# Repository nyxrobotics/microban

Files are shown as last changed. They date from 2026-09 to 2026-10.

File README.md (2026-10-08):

# Microban: A Compact, Fully 3D-Printable Open-Source Humanoid Robot





<p align="center">
  
  
  
</p>
  
Welcome to the **Microban** project! 

Microban is a ~30cm tall open-source humanoid robot created by [Marc Duclusaud](https://github.com/MarcDcls) as a member of the Rhoban team at LaBRI, University of Bordeaux, and designed specifically for makers, students, and robotics enthusiasts. The core philosophy behind this project is accessibility: the total cost of the robot is kept relatively low ($550-$600), all components are 3D-printable or easily sourced, and the assembly process is guided with detailed instructions. This means that anyone with a standard desktop 3D printer and a few basic tools should be able to build their own Microban from scratch.

The idea behind Microban is to provide a platform for learning and experimentation in robotics. By making the design open, users are encouraged to modify, improve, and share their own versions of the robot. Whether you're interested in programming, mechanical design, or electronics, Microban offers a hands-on experience that can help you develop your skills in a fun and engaging way.

The main features of Microban are:
*   🤖 **100% Open-Design**: Mechanics, 3D models, and documentation are entirely free to use and modify.
*   🔧 **DIY & Maker Friendly**: Guided assembly instructions, fully 3D-printable parts and cheap components.
*   📏 **Compact Size**: Microban is only 30cm tall and can be recharged via USB-C, making it the perfect desktop companion for robotics experimentation.

To see the robot take its first steps, check out this YouTube video: [https://youtu.be/1pnFrT_jfXQ](https://youtu.be/1pnFrT_jfXQ)

---

## 🛠️ Components Overview

Here is a quick overview of what is in the robot:

| Component | Quantity | Description / Notes |
| :--- | :---: | :--- |
| **3D Printed Parts** | ~30 | Check the CAD files. Recommended material is PETG-CF. |
| **Servo Motors** | 21 | Dynamixel XC330-T288-T servomotor. |
| **Microcontroller**| 1 | Raspberry Pi Zero 2W. |
| **Board Hat** | 1 | Pollen RPI Robot Hat for Raspberry Pi Zero 2W. |
| **Stereo Camera** | 1 | ELP-3DGS1200P01-H120 dual-lens (binocular) USB camera module, ~59mm measured baseline, mounted in the neck. |
| **Power Supply** | 3 | 18650 3.7V Lithium-ion Batteries. |
| **Battery Holder** | 1 | 3x18650 Battery Holder. |
| **USB-C Charger** | 1 | Standard USB-C charger. |
| **BMS** | 1 | Battery Management System for 3x18650 batteries. |
| **Plastic Screws**| ~200 | Standard plastic screws for assembly. |
| **Steel & POM Shims** | 12 | Alternative to needle bearings for motors without idler horns. | 

A full, detailed Bill Of Materials (BOM) with links to purchase and prices is available [here](docs/bom.md)

---

## 📁 CAD Files

Capture d’écran du 2026-06-15 13-33-16

The CAD files for Microban are in the `cad/` directory of this repository. It contains all the printable parts in both STL and STEP formats.

A visual representation of the 3D model can be found in the [Onshape assembly](https://cad.onshape.com/documents/d424992a192a8ce34ffce163/v/7de3e6e40f0e1185d169e6d9/e/b34620a03cc3a684006c5867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). This interactive assembly allows you to explore the robot's design in detail, providing a better understanding of how the parts fit together. It also serves as a reference for assembly, helping you visualize the final product and ensuring that you can correctly identify each component during the build process.

An emphasis is placed on the range of motion of the 21 degrees of freedom of the robot, which include a 2-DOF (roll + pitch) neck carrying a forward-facing stereo camera. It allows for a wide variety of movements, making it suitable for various applications. Stops are integrated into the design to control which self-collisions are likely to occur, ensuring that the robot can move safely without damaging itself. The design also takes into account the cable routing for the servo motors, ensuring that the wires are neatly organized and do not interfere with the robot's movements.

---

## 🚀 Getting Started 

> **Need help during the build?** 
> If you run into any issues while sourcing components, printing parts, or assembling your Microban, don't hesitate to ask the community in the **[Q&A Discussions section](https://github.com/Rhoban/microban/discussions/categories/q-a)**!

To build your own Microban, you will need to follow these steps:

1. **Source the hardware:** Gather the components listed in the [BOM](docs/bom.md). Links are provided to purchase each item, but feel free to source them from your preferred suppliers. Some components, like the Dynamixel motors, may have specific distributors depending on your location, which can impact the total cost. 

2. **Print the parts:** Head over to the `cad/stl/` folder and print all the parts using a 3D printer. The recommended filament is PETG-CF (carbon-fiber-filled PETG) with a layer height of 0.12mm and 100% infill. PETG-CF is abrasive, so print with a hardened steel (or similarly wear-resistant) nozzle rather than plain brass. Some parts require specific orientations for printing to ensure strength and proper fit. Refer to the [Printing Guide](docs/printing.md) for detailed instructions on how to print each part correctly.

3. **Assemble:** Follow our step-by-step [Assembly Guide](docs/assembly.md) to put the mechanics together.

4. **Deploy the software:** Once the robot is assembled, you can deploy the software on the Raspberry Pi Zero 2W by following the instructions in the [Deployment Guide](docs/deployment.md). 

5. **Drive it:** See the [Usage Guide](docs/usage.md) to run the robot, control it with the keyboard or a gamepad, and learn how to add your own moves.

---

## 🤝 Contributing

This project is community-driven! Whether it's designing a new head, writing code, or simply fixing typos in the documentation, contributions are always welcome. Feel free to fork the repository, make your changes, and submit a Pull Request. 

If you build your own Microban, don't hesitate to share it in the **[Show and Tell section](https://github.com/Rhoban/microban/discussions/categories/show-and-tell)**! 

If you just want to share ideas or chat about the project, you are also more than welcome to join the **[General Discussions](https://github.com/Rhoban/microban/discussions/categories/general)**.

---

## 📄 License & Commercial Use

Copyright (c) 2026 Marc Duclusaud.

This project uses a dual-licensing model to keep the project open for the community while protecting the author's work from unauthorized commercial exploitation.

* **Hardware & Documentation (CAD, STL, Docs):** Licensed under [CC BY-NC-SA 4.0](https://creativecommons.org/licenses/by-nc-sa/4.0/).
* **Software (Source Code):** Licensed under [GNU GPL v3](https://www.gnu.org/licenses/gpl-3.0.html).

To summarize the licenses:

* **Hobbyists, Makers & Researchers:** You are **100% free** to download, 3D-print, build, modify, and hack Microban for your personal, educational, or academic research use. If you share your modifications, you must release them under the same licenses.
* **Commercial Entities & Companies:** You **cannot sell this robot**, sell parts/kits, or use this hardware/software design in commercial products without prior explicit written permission.

### ⚠️ Commercial Inquiries

If you wish to manufacture, distribute, or sell products based on Microban (including selling pre-printed 3D parts, electronics kits, or fully assembled robots), you **must acquire a Commercial License**.

For licensing terms, commercial partnerships, or inquiries, please reach out to me on [LinkedIn](https://www.linkedin.com/in/marc-duclusaud/).

---

## 📚 Citation

If you use Microban in your research, please cite it as follows:

```bibtex
@software{mduclusaud-microban,
    author = {Duclusaud, Marc},
    doi = {10.5281/zenodo.20784789},
    month = jun,
    title = {{Microban: A Compact, Fully 3D-Printable Open-Source Humanoid Robot}},
    url = {https://github.com/Rhoban/microban},
    howpublished = "\url{https://github.com/Rhoban/microban}",
    version = {1.0.0},
    year = {2026}
}
```

---

<p align="center">
  
</p>

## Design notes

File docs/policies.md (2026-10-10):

# 学習したモデル（歩行・起き上がり・PICO）の契約と導入

実機は学習リポジトリ（mjlab_microban）で学習した 3 つのモデルを使う。

| モデル | ファイル | 使う動作 |
|---|---|---|
| 歩行 | `src/agents/walk.onnx` | `WalkMove`（GC300） |
| 起き上がり | `src/agents/getup.onnx` | `GetupMove`（転倒後の起き上がり、立位の保持） |
| PICO | `src/agents/pico_teleop.onnx` | `PicoHybridMove`（PICO の左トリガーで選ばれる全身の遠隔操作） |

3 つとも `src/policy_contract.py` の契約 `microban-policy-1` だけで照合する。
学習側との取り決めの全文は学習リポジトリ側と共有している契約の文書（metadata のキーの一覧）にあり、ここでは実機側の要点を書く。

## 契約
- 版: metadata の `microban_policy_contract` が `microban-policy-1`。観測・行動・目標の意味を変えたら、両方のリポジトリで手で上げる。
- 種類とレシピ: `microban_policy_kind`（walk / getup / pico）と `microban_recipe`。受け付けるレシピ id は `policy_contract.RECIPES` に 1 つずつ。
  PICO のモデルは、凍結した歩行器の出力に、学習した小さな補正の網（入力 81、隠れ層 64・64）の出力を足したもので、1 つのグラフになっている。レシピ id `microban-pico-arm-overlay-residual-track-velocity-1` はこの構造を表し、補正の網のない以前のモデル（`microban-pico-arm-overlay-track-velocity-1`）は拒否する。
- HOME: `home_pose` の全精度のスタンプと `default_joint_pos` が `config/home_pose.yaml` と 1e-6 以内で一致すること。別の HOME で学習したモデルは拒否する。
- 目標の式: どのモデルも `target = clip(HOME + raw * 1.0, -π, +π)`（18 関節、ソフトウェアのクリップなし、±π はサーボの 1 回転の範囲）。前回の行動の観測は生の出力。PICO だけは腕の 6 関節にこの式を使わない（下の「PICO の実行時の動き」）。
- 観測の並び: `observation_schema_json`（walk 63、getup 60、pico 81）と `observation_joint_names`。
- 合格: `gate_status=pass` と判定レポートの sha256。チェックポイントの名前と sha256。
- PICO だけ: 凍結した歩行器のチェックポイント（`pico_walk_checkpoint_sha256`）、足の目標の座標（HOME の体幹の傾きから決まる）と範囲、腕の目標（`pico_arm_target_json`: 関節の箱と速さ 4 rad/s が `pico_arm_contract` と同じ）、生の行動の上限（`pico_raw_action_guard_json`）、段の時刻（`critic_warmup / arm_start / foot_start / foot_tighten / total`。保存点が最後の段のものであること）、全部の追加列が学習されたこと。

実機側のソースのハッシュは使わない。互換性は契約の版と次の起動時の自己テストで確かめる。

## 起動時の自己テスト
各モデルには、書き出したチェックポイントの評価のロールアウトから取った観測 8〜64 行と、それに対する学習時の actor の出力が入っている。
実機は読み込むときにそれを ONNX Runtime に通し、行ごとに `max|ORT − 記録| ≤ 1e-4 + 1e-5 × max|記録|` を確かめる（PICO は加えて出力が上限以内）。
記録の観測は、重力のノルムが 1、関節角が可動範囲 + 5° の内側、関節速度が 12.1 rad/s 以下であること。
PICO の記録は、腕の目標が腕の箱の中にあり、腕の目標が 0 でない行と足の目標が 0 でない行を含むこと。

## manifest と導入
導入の道具（学習リポジトリの `scripts/retrain_all_for_home.py`）は次だけを書き、実機の .py もテストも書き換えない。

- `src/agents/walk.onnx`、`getup.onnx`、`pico_teleop.onnx`
- `src/agents/manifest.json`: 契約、HOME の tag、学習側の commit、試運転かどうか、各ファイルの sha256 とチェックポイントの sha256
- `config/home_pose.yaml`（schema 2）

実機はモデルを読むたびに、ファイルの sha256・チェックポイントの sha256・HOME の tag を manifest と照合し、
PICO は凍結した歩行器が導入された walk.onnx と同じチェックポイントであることも確かめる。
試運転のパッケージ（`dry_run`）は環境変数 `MICROBAN_ALLOW_DRYRUN_POLICY=1` のときだけ受け付ける（導入の検証とテストの実行のためだけ）。

検証（モーターのバスは開かない）:

```bash
PYTHONPATH=src uv run --locked python tools/validate_policies.py src/agents
PYTHONPATH=src uv run --locked --with pytest python -m pytest -q tests
make teleop-validate HOST=microban   # 作業機と Raspberry Pi の両方で validate_policies を実行
```

`make teleop-validate` は作業ツリーをそのまま rsync するので、`git status --porcelain=v1 --untracked-files=all` が空の状態で実行する。
通ってから `make teleop-run HOST=microban` で制御を始める。

### PICOだけを再学習した場合

同じHOMEと同じ歩行器からPICOだけを再学習した場合は、3モデル一括の
`retrain_all_for_home.py`ではなく、PICO専用の導入道具を使う。書き出しに使った
stage gateも渡すため、別の判定結果やcheckpointから作ったONNXは導入できない。

```bash
TRAINING_REPO=/absolute/path/to/mjlab_microban
PICO_RELEASE="$TRAINING_REPO/artifacts/pico_release/<run>"
TRAINING_COMMIT=<学習開始時にrunが記録した40桁のcommit>

PYTHONPATH=src uv run --locked python tools/install_pico_policy.py \
  "$PICO_RELEASE/pico_teleop.onnx" \
  "$PICO_RELEASE/model_14999_gate.json" \
  --training-repo "$TRAINING_REPO" \
  --training-branch tracking-v13c \
  --training-commit "$TRAINING_COMMIT" \
  --check-only

PYTHONPATH=src uv run --locked python tools/install_pico_policy.py \
  "$PICO_RELEASE/pico_teleop.onnx" \
  "$PICO_RELEASE/model_14999_gate.json" \
  --training-repo "$TRAINING_REPO" \
  --training-branch tracking-v13c \
  --training-commit "$TRAINING_COMMIT"

PYTHONPATH=src uv run --locked python tools/validate_policies.py src/agents
PYTHONPATH=src uv run --locked --with pytest python -m pytest -q tests
```

導入道具は、既存のwalk/getupを先に検証してそのbytesとmanifest欄を変えずに候補bundleへコピーし、
新しいPICOの契約、CPU自己テスト、stage gate hash、凍結walkerのcheckpoint hashを検証する。
さらにstage gateが指すcheckpointとrunの`git/mjlab_microban.diff`を読み、ONNX metadataに埋め込まれた
学習開始時のcommit・branch・Git記録hashと一致すること、そのcommitが指定branchに含まれることを確かめる。
現在のbranch先端（学習後の文書commitなど）を学習commitとして記録してはならない。

manifest上端の`training_commit`、`training_branch`、`home_yaml_sha256`、`created`は、保持したwalk/getupを含む
元の3-policy bundleの記録なので書き換えない。後から入れたPICOの出所は
`policy_provenance.pico`にcheckpoint、gate、ONNX、runのGit記録まで別に保存する。

3モデルをまとめた候補bundleが通った後にだけ`pico_teleop.onnx`と`manifest.json`を置き換える。
2ファイルは一度にはrenameできないため、導入前の両bytesとfsync済みjournalを
`src/agents/.pico-policy-install*`へ先に保存する。途中で電源断・killが起きた場合は、次にこの道具を
起動した時点で、完全な新しい組なら検証して確定し、途中の組なら古い組へ戻す。
復旧資料が壊れていて判断できない場合は上書きせず失敗する。正常終了時にはjournalもbackupも残らない。
同じbundleへの導入はlockで直列化し、atomic rename前に止まって残った専用tempも次回起動で除く。
`--check-only`を含むどの起動も、残っているtransactionの復旧だけは先に行う。
したがって差分はこの2ファイルだけでなければならない。

```bash
git status --short
git diff --stat
git diff -- src/agents/manifest.json
sha256sum src/agents/walk.onnx src/agents/getup.onnx
```

最後の2つのhashは導入前から不変であること。commit後にworktreeが空になってから
`make teleop-validate HOST=microban`を実行し、同じcommitをRaspberry Piへ同期して再検証する。

契約に合わないモデルの扱い:
- 歩行: `WalkMove` が例外を出し、そのランタイムは起動しない。
- 起き上がり: `GetupMove.model_ready` が False になり、転倒時はゆっくり初期姿勢へ戻るだけになる。
- PICO: `PolicySelectableWalkMove` が読み込みに失敗を記録し、左トリガーの間は最後の体の目標を保持する。

## サーボのゲイン
- 学習したモデル（歩行・起き上がり・PICO）が動いている間は、頭と首を含む全 21 関節を P125（`KP_RL`。学習の BAM と同じ値）。
- 学習したモデルを使わない静止（A の初期姿勢、起き上がり後に歩行が始まらないままの静止、起き上がりモデルが使えないとき、学習した動作が終わって HOME に戻ったあと）は全関節 P900（`KP_HARDWARE_NEUTRAL`）。
  PICO のモデルがない・失敗したときの静止保持（`policy_selector._HoldPositionMove`）も、何から引き継いだかによらず、保持する目標を送り直してから頭と首を含む全 21 関節を P900 にする。
- 右トリガーの腕の追従（`pico_arms`）は追従中だけ腕 6 関節を P125 にし、終わると歩行中なら P125、静止なら P900 に戻す。
- `RobotController.sync_write_kp` は前回そのサーボに送った値と違うものだけを送る。起動直後は値が分からないので、`main.py` の最初の書き込み（全関節 P900）は必ず全サーボに届く。サーボが通信から外れて戻ったとき（再起動で RAM のゲインが戻った可能性がある）は、最後に指定した値をそのサーボに送り直す。

## PICO の実行時の動き
- 入力は 81 個（角速度 3、重力 3、21 関節の角度と速度、前回の行動 18、速度指令 3、足の目標 6、腕の目標 6）。角速度は IMU の座標のまま。
- 腕の目標は、1 周期前に `pico_arms` が腕の 6 サーボに書いた目標角から HOME を引いた値（左 pitch, roll, elbow、右 pitch, roll, elbow。`PicoArmTargetHold` で受け渡す）。右トリガーを離していれば HOME に戻り 0 になる。
- 出力の 18 個はそのまま生の行動として前回の行動の観測に戻すが、サーボに使うのは脚の 12 個だけで、上の目標の式で目標にする。腕の 6 サーボには観測に使った腕の目標を書き、`pico_arms` が動いていれば同じ周期で上書きする。学習でも腕は外から同じ箱と速さで動かす。どれかが非有限、float32 で溢れる、または上限 `pico_raw_action_guard_json` を超えたら、目標を 1 つも書かずに例外を出し、selector が同じ周期で最後の体の目標を保持する（トリガーを離すまで保持を続ける）。
- 足の目標は学習の範囲で切り詰める。支持足の床の帯（z ≤ 2.5 mm）はちょうど 0 であること。両足を同時に上げる目標は学習の範囲の 0.8 倍以内で、速度指令が 0 のときだけ受け付ける。
- 左トリガーを押している間は `walk` が `active_moves` に入り、PICO のモデルにスティックの速度と体の目標を渡す。R3 で有効にしたまま左トリガーを離すと、速度 0・体の目標 0 で立位を保つ。右トリガーは `hmd_head`（首の追従）と `pico_arms`（腕の直接の追従）を有効にする。
- `MICROBAN_INPUT=network` の起動は全関節トルク OFF から始まる。右手 B はいつでも全関節のトルクを OFF にし、A は現在角を目標に書いてからトルクを ON にして 0.5 rad/s 以下で `NEUTRAL_POSE` へ戻す。R3 は A の後だけ、PICO のモデルと初期姿勢の復帰を切り替える。

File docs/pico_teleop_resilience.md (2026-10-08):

# PICO teleop degraded-operation contract

The PICO actor provides locomotion and R3 balance. The robot's `walk` move name
routes through `PolicySelectableWalkMove`. If the PICO actor cannot run, the
selector holds its last complete joint goals. At startup, before a PICO goal
exists, it holds the measured pose.

| Condition | Same-cycle result | Recovery |
|---|---|---|
| Camera stale/missing, calibration/FOV/IPD invalid | View may fall back to passthrough; locomotion is unchanged | Camera can recover independently |
| Optional foot targets missing, malformed, stale, or outside the wire envelope | Use zero offsets for missing feet; preserve left trigger, arms and joystick velocity | Valid tracking can resume without restarting the gait |
| Head tracking unavailable | Ignore that head pose; keep buttons, sticks, arms, and locomotion independent | Head tracking resumes when a valid pose arrives |
| PICO ONNX absent, rejected, or unable to start | Hold the last complete joint goals, or the measured pose if none were produced | Atomic replacement is loaded in the background and can be selected on a later activation |
| PICO inference fails or produces an unusable target | Hold the last complete PICO goals in the faulting control cycle | Keep the hold latched until locomotion is released and activated again |
| Left X / primary button changes | No locomotion effect; bridge keeps requesting `pico_teleop` | Left trigger enables walking; R3 enables zero-velocity balance |
| PICO controller samples or PC-to-robot UDP packets stop | Replay the last authenticated operator state, including motion, policy and torque state | Fresh input replaces that state when it arrives; a sender-authority change requires a new released-trigger snapshot |
| IMU becomes unavailable | Keep the previous motor goals and torque while policy output is inhibited | Valid IMU input allows the normal motion gate to resume |
| Robot falls in policy mode (R3 on) | After 0.3 s tilted beyond 60 deg, walking is inhibited and the get-up actor runs (20 s limit per attempt) | Once upright for 0.4 s, the get-up actor keeps balancing the robot until a walk move that can itself balance is requested at zero velocity and the trunk has stayed within 12 deg of the HOME attitude for 0.2 s (the hand-back waits for that settled stance); R3 off, B or an actor fault also end it. A new fall starts a fresh attempt |
| Get-up attempt exceeds 20 s or the actor output is non-finite | Latched fault: hold the measured pose at P900 and return slowly toward neutral | R3 off then on (or B) clears the fault and allows a new attempt |

After an automatic get-up, tracking does not resume on its own while the
operator keeps holding the triggers: the get-up actor keeps balancing. Release
the left trigger once after the robot is upright to hand the legs back to the
PICO policy (it takes over at zero velocity), and the right trigger for the
arm and head tracking; a release while the robot is still getting up does not
count. When
`src/agents/pico_teleop.onnx` fails its contract or startup self-test
(docs/policies.md), the legs fall back to the static position hold, which
cannot balance: the get-up actor then keeps the robot standing until R3 is
switched off, and a policy package of the current contract must be installed
to restore tracking.

An explicit B press turns torque off. A changes to the neutral-return mode; R3
selects the PICO policy for balance even with the left trigger released. Missing
tracking data and packet gaps do not synthesize A or B events. Before the first
authenticated operator snapshot, the hardware gate stays in its startup state.
The A/B servo-bus command is a broadcast sync-write. Because that packet has no
per-servo acknowledgement, the runtime reads the torque-enable registers before
resuming normal control. It retries IDs whose state differs from the command
for up to about one second and reports any that remain unconfirmed. A starts the
neutral return for confirmed joints while continuing ON retries for the others.
OFF cancels pending ON retries first; unresolved IDs also receive slower
background checks. The limp loop does not send goal positions. A seeds measured
goals before enabling torque when feedback is available. If an initial position
reply is missing, it seeds that joint directly to neutral and enables it without
waiting for a position read; that joint may move directly to neutral. During the
A return, subsequent position reply failures do not stop feedforward neutral
goals. During policy output, a joint with a missing position reply is resent its
previous goal until feedback returns.

The focused non-hardware regression command is:

```bash
PYTHONPATH=src uv run --with pytest python -m pytest -q \
  tests/test_policy_selector.py tests/test_network_input.py
```

These tests do not open the motor bus or launch the physical gateway. They cover
selector fallback holding, optional-tracker isolation, packet-to-selector
activation, atomic-file reload, and replay of authenticated operator input.

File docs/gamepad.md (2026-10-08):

# Gamepad control through Bluetooth

The robot can be driven with a Bluetooth gamepad (Xbox or compatible). The gamepad
is paired with the Raspberry Pi and read directly there via the Linux joystick API
(`/dev/input/js*`), in the same process as the control loop. 

Pairing a gamepad allows to drive the robot through two different modes: with a terminal (SSH) or fully headless (no SSH, no terminal). The second mode is particularly useful for demonstration purposes, 
due to the fact that it allows to drive the robot without any computer connected to it. 

## Pairing the controller on the Pi

On the Pi, put the Xbox controller in pairing mode (hold the pair button until the
Xbox light flashes fast), then:

```
bluetoothctl
[bluetooth]# power on
[bluetooth]# agent on
[bluetooth]# scan on        # wait for the "Xbox Wireless Controller" MAC to appear
[bluetooth]# pair  XX:XX:XX:XX:XX:XX
[bluetooth]# trust XX:XX:XX:XX:XX:XX    # auto-reconnect on next power-on
[bluetooth]# connect XX:XX:XX:XX:XX:XX
[bluetooth]# scan off
[bluetooth]# quit
```

Once paired and trusted, the controller reconnects automatically when powered on.

## SSH usage

When the controller is connected, the `make run` command uses it as input automatically instead of the keyboard. The mapping is:

- **B**: all-joint torque off. The control loop starts with torque off.
- **A**: torque on, and a slow return of every joint to HOME (learned policies withheld)
- **R3** (right stick click): toggle the learned policies (only while torque is on)
- **X**: toggle the `walk` move
- **Left stick**: `vx` (up/down), `vy` (left/right)
- **Right stick** (left/right): `vtheta`
- **START**: stop the scheduler (writes the stop flag)
- **View/Back** button: toggle the IMU/gyro display

B, A and R3 are reserved for this gate and cannot be reassigned. In `make run`
(`src/main.py`) the `walk` move holds the current pose; walking runs from the PICO
controller ([Teleoperation](teleop.md)) or the GC300 runtime ([GC300](gc300.md)).

Axis and button numbers vary between controllers (especially over Bluetooth) — if
something doesn't respond as expected, see [Remapping](#remapping-for-your-controller).

Every input source emits a **normalized** command in `[-1, 1]` per axis. The physical
limits are applied centrally by `scale_velocity()` in the scheduler, so they are
identical for keyboard, gamepad and sim: `vx` ±0.7, `vy` ±0.3, `vtheta` ±3.0 when
turning in place (`vx = vy = 0`) and ±1.5 while translating. Tune these via
`VX_MAX` / `VY_MAX` / `VTHETA_MAX_STATIONARY` / `VTHETA_MAX_MOVING` in
[constants.py](../src/constants.py).

Signs, deadzone and button mapping are constants at the top of
[gamepad_input.py](../src/input/gamepad_input.py); the move/button mapping is set
via `GAMEPAD_BUTTON_MOVES` in [main.py](../src/main.py).

## Headless mode (no SSH)

The headless mode is an optional service that lets you run the robot **without any terminal**. To activate it, power off the controller, then run the following commands on your computer:

```
make gamepad-headless-enable
```

Once enabled, it launches a daemon on the Pi that waits for a controller to connect over Bluetooth. Once a controller is connected, the Wi-Fi is turned off to free the 2.4 GHz antenna and the following commands are available on the controller:

- **Hold START** → start the control loop (torque off until **A**).
- **B / A / R3 / X** → the same roles as in the SSH usage above.
- **START** → stop the control loop.
- **Hold both triggers** → power off the Pi cleanly. Wait 10-15 s after that before
  flipping the robot's power switch off, to give the Pi time to actually halt.

The headless mode persists across reboots, which means that you don't need to connect to the Pi over SSH to enable it again. It is particularly useful for demonstration purposes, as it allows to drive the robot without any computer connected to it.

If the **controller disconnects** during a session, the velocity is zeroed and all
joint torque is cut. Reconnect and press **START**, or power off the robot, to end the session.

Whenever the daemon is left with no controller connected — because it disconnected,
because the control loop crashed, or because the robot just booted — Wi-Fi is
(re)enabled automatically. You don't need to power-cycle the robot to get SSH back;
simply turning the controller off is enough.

> [!IMPORTANT]
> As the Wi-Fi is turned off when the controller is connected, so you won't be able to connect to the Pi over SSH while the controller is connected. If you need to connect to the Pi over SSH, power off the controller

To disable the headless mode, run the following command (after powering off the controller):
```
make gamepad-headless-disable
```

## Remapping for your controller

Xbox controllers don't all expose the same axis/button numbers — over Bluetooth the
kernel often uses a different layout than the wired `xpad` one. If a stick or button
doesn't behave as expected, find the real numbers and update the constants.

This requires an SSH session, so headless mode must be disabled first (see above) —
otherwise Wi-Fi is off while the controller is connected and you won't be able to
reach the Pi. You'll also need the controller connected.

1. Install the joystick package on the Pi:
```
sudo apt install -y joystick
```

2. Run `jstest /dev/input/js0`, then move each stick and press each button one at a
   time, noting the `Axis N` / `Button N` that changes:

   | Action | Note the number |
   | :--- | :--- |
   | Left stick horizontal / vertical | `Axis` → `_AXIS_LX` / `_AXIS_LY` |
   | Right stick horizontal | `Axis` → `_AXIS_RX` (drives `vtheta`) |
   | A / B / X / R3 / Back / Start | `Button` → `XBOX_BUTTONS` |
   | Left / right trigger | `Axis` → `TRIGGER_AXES` (headless power-off gesture) |

3. Edit the constants at the top of
   [gamepad_input.py](../src/input/gamepad_input.py):
   - `_AXIS_LX`, `_AXIS_LY`, `_AXIS_RX` — the stick axis numbers.
   - `XBOX_BUTTONS` — the button name → number map (at least the ones you use).
   - `TRIGGER_AXES` — the `LT` / `RT` axis numbers, and `TRIGGER_PRESS_THRESHOLD` —
     the raw axis value that counts as "pressed".
   - `VX_SIGN`, `VY_SIGN`, `VTHETA_SIGN` — flip between `+1.0` / `-1.0` if a direction
     is reversed.

4. Which button does what is set by `GAMEPAD_BUTTON_MOVES` in
   [main.py](../src/main.py) (moves) and the `stop_button` / `imu_button` arguments of
   `GamepadInputSource` (defaults: stop = `START`, IMU = `BACK`). B, A and R3 cannot be
   reassigned.

The defaults shipped in the repo (A=0, B=1, Start=11; left stick = axes 0/1, right
stick horizontal = axis 2, triggers = axes 4/5) are verified on an Xbox controller
over Bluetooth — but the exact axis numbers, rest/press values and button mappings are known to vary
across pads, so double-check with `jstest` on yours.

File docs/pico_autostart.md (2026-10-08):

# PICO実機テレオペのロボット自動起動

ロボット側はsystemd system serviceで、PICO network runtimeとcamera latest-snapshot mTLS proxyを
自動起動できます。既存のgamepad headless serviceとは競合させず、送信元PCを1つのIPv4 addressへ固定します。

## 初回設定

PC側のIPv4 addressを確認し、ロボットへ同期済みのrepositoryで次を実行します。

```bash
cd /home/user/microban
sudo bash systemd/configure-pico-services.sh install --allowed-ip 192.168.8.177
sudo bash systemd/configure-pico-services.sh enable
```

`install`はunitを検証・配置するだけでprocessを起動しません。cameraを使わないcontrol-only構成では
`--without-camera`を付けます。camera付き構成は既存`microban-camera.service`と、事前に
`systemd/provision-camera-tls.sh`で生成したrobot側identityを要求します。

## 管理

```bash
sudo bash systemd/configure-pico-services.sh status
sudo bash systemd/configure-pico-services.sh health
sudo bash systemd/configure-pico-services.sh logs
sudo bash systemd/configure-pico-services.sh restart
sudo bash systemd/configure-pico-services.sh disable
sudo bash systemd/configure-pico-services.sh enable
sudo bash systemd/configure-pico-services.sh uninstall
```

`enable`は競合する`microban-gamepad.service`（ゲームパッドのheadlessモード）とGC300ランタイムを停止・無効化してからPICO runtimeを起動します。
GC300の単独操縦に切り替えるときは[GC300操縦手順](gc300.md)の`configure-gc300-runtime.sh enable`を実行します。
両モードの切替時はランタイムを停止するため、一度トルクOFFになります。

`status`は設定した構成のsystemd状態を表示し、`health`はenable/active、GC300・gamepad headlessモードとの競合、UDP 5555、
camera構成時のHTTP 8080/TLS 8443 listenerまで検査して、未準備なら非zeroで終了します。cameraを使わない
`--without-camera`構成では、存在しないcamera unitを異常扱いしません。runtimeとTLS proxyは一時的な
network、camera、serial障害が長時間続いても再起動上限で停止せず、復旧を待ち続けます。

PICO runtimeは`MICROBAN_SERIAL_HOLD_LAST_ON_ERROR=1`で動きます。21台のどのサーボでも位置・速度などの
同期読取に失敗した周期は、最後の正常な観測値と送信済み目標を保持し、新しい動作目標を送信しません。
送信でエラーが出た場合も動作計算を止め、直前の送信済み目標を再送して通信復旧を待ちます。欠けた読取値や
非有限値も通信エラーとして扱います。Aボタンの初回目標送信など、hardware gate内の送信が失敗した場合も
次の周期で再試行します。連続して0.3秒以上エラーが続いた後は、復旧時に歩行トリガーの離し直しが必要です。
通信エラーだけを理由に全関節のトルクを切る処理は行いません。

`disable`はruntimeを先に停止し、その終了処理と独立したall-joint torque-off helperを実行してからcamera proxyを
停止します。`uninstall`は既存のuStreamer service、camera証明書・秘密鍵、学習済みONNXを削除しません。
gamepad headless unitとはsystemd上でも競合させています。手動runtimeのPIDが既にmotor busを所有している場合も、
serviceのpre-start helperはそのsessionへ割り込んでtorqueを変更せず、起動を失敗させます。

## 起動時の状態遷移

serviceは`MICROBAN_INPUT=network`と`MICROBAN_START_TORQUE_OFF=1`を固定し、通常runtimeの前にも独立した
all-joint torque-offを実行します。起動前・終了後のhelperはブロードキャストOFF後に各IDを読み戻し、
未確認のIDへ約1秒間再送します。期限時に無応答のIDはログに残し、OFF以外を読み戻したIDが残る場合は
起動を失敗させます。boot、service restart、PC/PICO再接続だけではtorque ONを指令しません。

1. 起動直後: 全関節torque OFF、policy OFF。
2. PICO右手A: torque ON、policyはOFFのまま、全関節を低速で初期姿勢へ移動。
3. 右stick押し込み: 初期姿勢待機とpolicy有効をtoggle。
4. PICO右手B: 即時に全関節torque OFF、policy OFF。

最初の認証済み操作を受けた後にUDPパケットが途切れても、最後の操作状態を再利用して歩行ポリシーを
継続します。PICOの一時的な入力欠落についても、PC bridgeが送る`torque_enabled=false`だけでは
トルクを切らず、右手Bを示す`torque_off_requested=true`を受けたときだけトルクを切ります。
起動後の初回パケット前と送信元PCの切替時は、前回の関節目標とトルク状態を保持します。
PC bridgeが新しいセッションで再起動した場合、歩行の再開には左トリガーを一度離してください。
単なるUDP断の復旧では、Aや右stick押し込みを操作し直す必要はありません。

これは物理非常停止の代替ではありません。実機確認は支持治具を使い、別の人が電源へ手を届かせた状態で行って
ください。

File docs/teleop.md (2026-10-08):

# PICO 4 Ultra network teleoperation

PICO側のPC bridgeは隣の `microban_teleop` リポジトリにあります。このリポジトリにはロボット側の
UDP入力、歩行deadman、HMD首3軸制御、カメラstream serviceを置いています。

## 起動

最初は実機ではなくMuJoCoで確認します。

```bash
make teleop-sim
```

カメラ校正と支持治具上のacceptanceが完了した後だけ、実機を起動します。

```bash
make teleop-run
```

これはSSH接続元IPだけを許可して、UDP port 5555でfull-snapshot JSONを受信します。手動起動なら:

```bash
MICROBAN_INPUT=network \
MICROBAN_NETWORK_ALLOWED_IP=192.168.8.177 \
PYTHONPATH=src .venv/bin/python src/main.py
```

環境変数:

| 変数 | 既定値 | 内容 |
|---|---:|---|
| `MICROBAN_NETWORK_PORT` | `5555` | UDP受信port |
| `MICROBAN_NETWORK_ALLOWED_IP` | 未指定 | 指定時、このIPv4送信元だけ許可 |

## robot-side safety

- packetは部分更新ではなく完全snapshot。省略fieldはneutral。
- version/session/sequenceを確認し、同一sessionの古いpacketを破棄。
- 起動・新session・許可する送信元の変更の後、一度`walk`なしpacketを受けるまで歩行を禁止。
- 受信が途切れても、最後に受けた操作を保つ。止めるのはB（トルクOFF）のpacketだけ。
- malformed JSON、NaN/Inf、未知moveを破棄し、受信threadを継続。
- `pico_teleop`は固定contract tag、安全余裕0.8、左右の手足pair、80% target範囲をrobot側でも検証。
  違反packetは速度・targetを即時clearし、左triggerのreleaseまで再armしない。
- IMUがinvalid、100 ms超のstale、または非finiteになった瞬間から、直前の関節目標とトルクを保持し、
  ポリシー出力を止める。
- IMU異常後は、左triggerのreleaseを再観測するまで歩行を再許可しない。
- 歩行解除時、18 policy軸を0.8秒のsmoothstepで初期姿勢へ戻してからKPを戻す。
- HMD首指令はyaw/roll/pitchのjoint limitとslew limitをrobot側でも適用。

## カメラ

USBステレオカメラ接続後、2通りの配信方法があります。どちらも同じUSBカメラを排他利用するので
同時には動かせません。**デフォルトはH264/UDP(ハードウェアエンコード)を使ってください**。MJPEG/HTTP
はブラウザで手軽に確認したい場合向けに残しています。

### H264/UDP (`camera-stream-udp`, デフォルト・低遅延・高fps)

```bash
sudo apt-get install -y ffmpeg  # ロボット側、初回のみ
make camera-stream-udp
```

Piの`camera-stream-enable`サービスは事前に止めてください(`ssh microban sudo systemctl stop microban-camera`)。
実行したマシンのIPを自動検出し(`teleop-run`と同じ`SSH_CONNECTION`の仕組み)、GPUハードウェアH264エンコード
(`/dev/video11`, bcm2835-codec-encode)でエンコードしたMJPEG→H264をUDP/MPEG-TSでそのマシンへ直接送ります。
1280x480で実測ほぼフル60fps(MJPEG/HTTPの32fpsに対して大幅に高い)。受信・表示は同じマシンから別ターミナルで:

```bash
make camera-view-udp
```

止めるときは必ずCtrl+C(SIGINT)で。`kill -9`で強制終了すると`/dev/video11`(GPUのH264エンコーダ)が
再初期化できなくなることがあり、その場合はPiの再起動が必要です。

### MJPEG/HTTP (`camera-stream-enable`, ブラウザで手軽に見たいとき用)

```bash
make camera-stream-enable
```

systemd unitは`http://microban:8080/stream`でMJPEGを公開します。設定はロボット側の
`/etc/default/microban-camera`です。カメラ未接続の状態でこのinstall targetを実行しないでください。
ブラウザ等どこからでも見れますが、Pi Zero 2Wの2.4GHz WiFi帯域に対してMJPEGは1フレームが大きすぎて、
1280x480でも実測32fps程度が上限です。

### PICO校正済み表示向けTLS latest-snapshot

連続`/stream`はclientがWi-Fi帯域より遅いと古いJPEGがsocket queueへ溜まります。校正済みPICO表示では
uStreamerの最新1枚だけを取得し、撮影時刻headerとJPEGをmutual TLS 1.3で保護するproxyを使います。
robotとPCは相互に、provision時に交換した自己署名leaf certificateだけを信頼します。server certificateの
pinningだけをclient認証とは見なしません。

```bash
make camera-stream-tls-provision
make camera-stream-tls
```

robotのserver秘密鍵は`~/.config/microban-camera-tls/server.key`から、PCのclient秘密鍵は
`~/.config/microban-teleop/microban-camera-client.key`から出ません（いずれもowner-only）。SSHで交換するのは
公開certificateだけです。別PCでprovisionし直すと、robotが許可するclient certificateはそのPCのものへ
置き換わります。

`camera-stream-tls`はforegroundで動き、Ctrl+Cで終了します。既存uStreamerも必要です。proxyが転送するのは
認証済みclientからの`/snapshot`だけで、V4L2 dequeueからresponse header生成までのuStreamer monotonic
timingとrobot wall clockを改変せず保持します。TLSはraw TCPをacceptしてから上限付きworker内でhandshakeし、
既定で同時4接続、handshake 1秒、HTTP inactivity 1秒、1 request全体2秒に制限します。不完全なTLS接続1本が
accept loopを止めることはありません。

PC側の表示は `../microban_teleop/docs/physical_camera_gateway.md` を参照してください。

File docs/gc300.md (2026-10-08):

# MSI FORCE GC300 WIRELESSでロボットを単独操縦する

GC300をロボットのRaspberry PiにBluetooth接続します。操縦中にPCやPICOは不要です。
ロボットのWi-Fiは有効のままです。古い`microban-gamepad.service`はBluetooth接続時にWi-Fiを
切るため、この構成では使いません。

## 初回のBluetooth接続

GC300の無線モードをBluetoothマークにし、Dragonボタンを長押ししてLEDを青点滅にします。
ロボットへSSH接続して、次を実行します。

```bash
bluetoothctl power on
bluetoothctl pairable on
bluetoothctl --timeout 30 scan on
bluetoothctl pair XX:XX:XX:XX:XX:XX
bluetoothctl trust XX:XX:XX:XX:XX:XX
bluetoothctl connect XX:XX:XX:XX:XX:XX
bluetoothctl info XX:XX:XX:XX:XX:XX
jstest --event /dev/input/js0
```

表示名は`MSI FORCE GC300 WIRELESS`です。上記の`XX:...`はスキャンで表示されたMACアドレスに
置き換えます。接続後の`/dev/input/js*`はロボット側にできます。
入力の割り当ては、左スティックが軸0/1、右スティックが軸2/3、LTが軸5、Aがボタン0、Yがボタン3、
Xがボタン4です。

## ロボット起動時からGC300を使う

ロボット上のこのリポジトリで、一度だけ次を実行します。

```bash
sudo bash systemd/configure-gc300-runtime.sh install
sudo bash systemd/configure-gc300-runtime.sh enable
```

`enable`はPICOランタイムを停止し、GC300ランタイムを今すぐ起動して次回のロボット起動にも登録します。
GC300をまだ接続していなくてもランタイムは起動し、接続を待ちます。起動直後はトルクOFFです。
GC300を使う間にPCは不要です。歩行・立位にはロボット内の`src/agents/walk.onnx`を使います。
歩行・PICO全身追従・起き上がりの全ポリシーは、同じ1つの基準姿勢（HOME。`config/home_pose.yaml`から
読む`src/constants.py`の`NEUTRAL_POSE`）と同じ目標式
`target = clip(HOME + 生の出力 * 1.0, -π, +π)`を使い、前回の生の出力を観測します。
ソフトウェアのクリップはなく、上下限はサーボ自身の1回転分の目標位置範囲（±π）だけです。
`walk.onnx`は全モデル共通の契約`microban-policy-1`（`config/home_pose.yaml`と一致するHOME、
目標の式、起動時の自己テスト、`src/agents/manifest.json`との照合。[学習したモデルの契約と導入](policies.md)）を
満たす必要があり、満たさない場合は起動時に読み込みを拒否します（GC300ランタイムは起動しません）。
モデルは学習リポジトリの`scripts/retrain_all_for_home.py`が3つ一緒に導入します。導入したあと
`microban-gc300-runtime.service`を再起動します。起動時はいったんトルクOFFになります。

| GC300操作 | 動作 |
| --- | --- |
| A | トルクON、初期姿勢への移動、ポリシーOFF |
| B | トルクOFF |
| 右スティック押し込み（R3） | 立位・歩行ポリシーON/OFF |
| Y | AでトルクONにした後、人追従を開始。ポリシーOFFなら自動でON |
| X | 人追従を終了。トルクと歩行ポリシーは維持 |
| LTを保持 | ポリシーON中に歩行。離すと立位バランス |
| 左スティック | 前後・左右の速度 |
| 右スティック左右 | 旋回速度 |

Aを押して初期姿勢への移動が終わってから、単独の立位・歩行はR3、
人追従はYで開始します。LTは接続やA操作の後に一度離すと
歩行が有効になります。右トリガーとグリップに相当するPICOの頭・腕追跡機能は使いません。
GC300のAで移動する初期姿勢と、R3でポリシーをOFFにした後の戻り先は、どちらも`NEUTRAL_POSE`（HOME）です。
実機のサーボ取り付けずれなどを補正したい場合は、入力方式に関係なくすべての動作（歩行・PICO・起き上がり・
A/R3の中立姿勢・腕・頭/首）に共通の実機オフセット`src/constants.py`の`HARDWARE_JOINT_OFFSET_DEG`
（全21関節、初期値はすべて0）を使います。詳しくは[Usage](usage.md#real-robot-joint-offsets)を参照してください。
例えば両足首を1度前傾させたい場合は、`left_ankle_pitch`と`right_ankle_pitch`を`-1.0`にします。
GC300のSTARTなどは操作に割り当てていません。GC300の通信が途切れても自動で
トルクOFFにはしません。切断後1秒までは前回の操作を継続し、その後は速度目標だけゼロにして
ポリシーの更新を続けます。1秒以上の切断後に再接続した場合は、LTを一度離してから歩行を再開します。

ポリシーON中（R3後）に転倒すると、約0.3秒後に自動で起き上がりを始めます。起き上がって
約0.5秒直立すると、制御は立位バランス（歩行ポリシー、速度0）に戻ります。歩行を再開するには、
起き上がった後にLTを一度離してから押し直してください。LTを握ったままでは歩き出さず、その場で
立ち続けます。起き上がりの途中で離して押し直しても数えられないので、起立後にもう一度離します。
起き上がりモデル`src/agents/getup.onnx`も同じ契約を満たす必要があり、満たさない場合は無効になり、
転倒時はゆっくり初期姿勢へ戻るだけになります。

Yの追従は別リポジトリ`microban_person_tracking`の顔検出サービスを使います。顔が見えない・
映像が古い場合は追従の速度指令を0にし、首の向きを最大1秒保持してから約40度上向きにして
顔を探します。カメラは床から約32 cmの高さにあり、正面を向いたままでは近くの人の顔は
画角に入りません。
顔が見えた場合は、画像上の顔幅と見上げ角から床面上の距離を概算し、約0.6 m以下では
前進を止めます。顔幅は12 cmと仮定するため、実際の停止距離は人や顔の向きで変わります。
顔への見上げ角が75度以上でも前進を止めます。首の目標角には別途約69度の上向き上限があります。
ステレオ深度や障害物検出は使っていません。
A/B/R3やLTでの手動操作は通ります。LT中は手動の
速度指令を優先し、Yの追従中だけ首が顔を向きます。A/B、またはR3でポリシーをOFFにすると
追従も解除します。ゲームパッドが1秒以上切れた場合は、再接続後にYを押し直します。
YはポリシーOFF中でも自動でポリシーをONにします。トルクOFF中は先にAを押す必要があり、
AとYが同じ制御周期に入った場合はYを押し直すようログに記録します。

状態の確認:

```bash
sudo bash systemd/configure-gc300-runtime.sh status
journalctl -u microban-gc300-runtime.service -f
bluetoothctl info XX:XX:XX:XX:XX:XX
```

PICO操縦に戻す場合は`sudo bash systemd/configure-gc300-runtime.sh pico`を実行します。
この切替では現在のランタイムを止めて一度トルクOFFにします。PICOのAとR3で再開します。

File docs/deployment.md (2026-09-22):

# Software Installation & Deployment

This guide takes you from the pre-built Microban SD-card image to a robot you can drive
from your computer. The image already contains the operating system and the Microban
code; you will flash it, connect to the robot over the network, and run it. For
day-to-day operation and development afterwards, see the [Usage Guide](usage.md).

## Step 1: Download and Flash the Image

Download `microban.img.xz` from the
[latest image release](https://github.com/MarcDcls/microban/releases/tag/image.v2)
([direct link](https://github.com/MarcDcls/microban/releases/download/image.v2/microban.img.xz)).
There is no need to decompress it; Raspberry Pi Imager reads the compressed `.xz`
directly.

Then use [Raspberry Pi Imager](https://www.raspberrypi.com/software/) to write
`microban.img.xz` onto a micro-SD card. The card should be 16 GB or larger, and I
advise using a new card, as corrupted cards can cause issues.

1. Insert the micro-SD card into your computer.
2. Open Raspberry Pi Imager. It is distributed as an AppImage, so make it executable
   and run it as root to let it write to the SD card:
   ```bash
   chmod +x Downloads/imager_*.AppImage
   sudo Downloads/imager_*.AppImage
   ```
3. **Choose Device** → *Raspberry Pi Zero 2 W*.
4. **Choose OS** → scroll to the bottom and select *Use custom*, then pick the
   `microban.img.xz` file.
5. **Choose Storage** → select your micro-SD card.
6. Click **Next**. When asked *"Would you like to apply OS customisation settings?"*,
   choose **No** — the image is already configured (the Wi-Fi is set up in Step 2).
7. Click **Write** and wait for the flashing and verification to complete.

> Alternatively, on Linux you can flash from the command line. **Double-check the
> device name** (`lsblk`) — writing to the wrong disk will erase it:
> ```bash
> xzcat microban.img.xz | sudo dd of=/dev/sdX bs=4M status=progress conv=fsync
> ```

## Step 2: Headless Wi-Fi Configuration

Once the flashing process is complete, unplug and plug back the micro-SD card into your Ubuntu PC. Both the `bootfs` and `rootfs` partitions get mounted.

📶 CRITICAL: the network **must be 2.4 GHz**. The Raspberry Pi Zero 2 W has a 2.4 GHz-only
Wi-Fi chip and **cannot see or join a 5 GHz network** — it will silently never connect. If
you use a phone hotspot, force it to 2.4 GHz.

Wi-Fi is configured by writing a NetworkManager connection profile directly onto
`rootfs` (**not** by editing `network-config` — see why below). Generate a UUID and
write the profile:

```bash
UUID=$(uuidgen)
sudo tee /media/$USER/rootfs/etc/NetworkManager/system-connections/home.nmconnection >/dev/null <<EOF
[connection]
id=<YOUR_WIFI_NAME>
uuid=$UUID
type=wifi
autoconnect=true

[wifi]
mode=infrastructure
ssid=<YOUR_WIFI_NAME>

[wifi-security]
key-mgmt=wpa-psk
psk=<YOUR_WIFI_PASSWORD>

[ipv4]
method=auto

[ipv6]
method=auto
addr-gen-mode=default

[proxy]
EOF
sudo chown root:root /media/$USER/rootfs/etc/NetworkManager/system-connections/home.nmconnection
sudo chmod 600 /media/$USER/rootfs/etc/NetworkManager/system-connections/home.nmconnection
```

⚠️ CRITICAL: the file must be owned by `root:root` with `600` permissions, or
NetworkManager silently ignores it.

🛜 Replace both `<YOUR_WIFI_NAME>` and `<YOUR_WIFI_PASSWORD>` with your local network
credentials. To also reach the robot on a second network (e.g. a phone hotspot), repeat
the block above with a different file name (e.g. `hotspot.nmconnection`) — the robot
tries every profile it has and connects to whichever is in range.

Safely eject the card from your Ubuntu PC, insert it into the Raspberry Pi Zero 2W, and power it up.

> **Why not `network-config`?** That file still exists on `bootfs`, and it looks like the
> obvious place to set Wi-Fi — but on this image, cloud-init's Wi-Fi config never gets
> turned into an actual NetworkManager connection (a cloud-init module it depends on,
> `cc_netplan_nm_patch`, is missing from this image). It validates with no error and
> silently does nothing, so the robot never joins your network. Leave `network-config` at
> its placeholder values and use the `.nmconnection` method above instead.

> **Changing the Wi-Fi network later:** with the SD card back in your PC, add, replace, or
> delete `.nmconnection` files under `rootfs/etc/NetworkManager/system-connections/` the
> same way, then reboot the Pi. If you already have SSH access, you can instead run
> `sudo nmcli device wifi connect "<SSID>" password "<PASSWORD>"` directly on the Pi.

> **Country / regulatory domain:** this method does not set the Wi-Fi regulatory domain,
> so channels 12–13 stay unavailable. Most routers default to channel 1, 6, or 11, so this
> rarely matters; if you need those channels, run
> `sudo raspi-config nonint do_wifi_country <CC>` once you have SSH access.

## Step 3: First SSH Connection

Give the Raspberry Pi about 1 to 2 minutes on its very first boot. It will automatically resize the file system to use the full capacity of your SD card and then connect to your Wi-Fi network. Do not power it off during this process, as it may take a while and interrupting it could cause issues.

When the Pi is ready, you should be able to ping it from your computer using the command:

```bash
ping microban.local
```

You should see a response looking like this:
```
PING microban.local (192.168.XXX.XX) 56(84) bytes of data.
64 bytes from 192.168.XXX.XXX: icmp_seq=1 ttl=64 time=100 ms
...
```

The default credentials of this image are:
- Username: `user`
- Password: `password`

Open your terminal and connect over SSH:

```bash
ssh user@microban.local
```

> If `microban.local` cannot be found after 5 minutes, look up your local router's DHCP client list
> to find the IP address assigned to the Pi, and connect with `ssh user@<IP>`.

## Step 4: Personalize and Secure Your Robot

Once you are successfully connected via SSH, change the default password and,
optionally, customize the hostname.

### Change the password

Run the password tool and follow the prompts:
```bash
passwd
```

Apply the changes:
```bash
sudo reboot
```

### OPTIONAL - Change the username

The image ships with the user `user`. A logged-in account cannot be renamed, so create
a temporary admin account, rename from there, then remove it. Replace `NEW_USER` with
your choice.

From the default `user` session, create a temporary admin and set its password:
```bash
sudo useradd -m -s /bin/bash -G sudo tmpadmin
sudo passwd tmpadmin
```
Log out, reconnect as `tmpadmin`, then rename the original account:
```bash
ssh tmpadmin@<ROBOT_IP>
sudo usermod -l NEW_USER -d /home/NEW_USER -m user
sudo groupmod -n NEW_USER user      # rename its primary group too
```
Log out, reconnect as `NEW_USER`, and delete the temporary account:
```bash
ssh NEW_USER@<ROBOT_IP>
sudo userdel -r tmpadmin
```
The shutdown-without-password rule still works (it targets the `sudo` group, not a
name). Remember to update the `User` field in your `~/.ssh/config` (Step 5).

Apply the changes:
```bash
sudo reboot
```

### OPTIONAL - Change the hostname

Rename your robot so it no longer answers to `microban` on the network:
```bash
sudo hostnamectl set-hostname NEW_ROBOT_NAME
```
Then update the hosts file to match:
```bash
sudo nano /etc/hosts
```
Find the line containing `microban` (usually the second line) and replace it with your
`NEW_ROBOT_NAME`. Save and exit (Ctrl+O, Enter, Ctrl+X).

Apply the changes:
```bash
sudo reboot
```

## Step 5: Deploy the Software from Your Computer

The code already ships on the robot, but you drive and update it from your computer
using the provided `Makefile`, which syncs your local copy to the Pi over SSH and
installs the dependencies there.

1. **Install [uv](https://docs.astral.sh/uv/)** (the Python package manager) on your
   computer:
   ```bash
   curl -LsSf https://astral.sh/uv/install.sh | sh
   ```

2. **Clone the repository** on your computer:
   ```bash
   git clone https://github.com/MarcDcls/microban.git
   cd microban
   ```

3. **Add SSH aliases** so the Makefile can reach the Pi. Add the following to your
   `~/.ssh/config`, replacing `user` if you changed it and `<IP_ADDRESS>` with the
   robot's IP on each network:
   ```
   # Main network
   Host microban
       HostName <IP_ADDRESS>
       User user

   # Secondary network / phone hotspot
   Host microban-ext
       HostName <IP_ADDRESS>
       User user
   ```
   To find the robot's IP on a given network ping it from your computer while connected to that network:
   ```bash
   ping microban.local
   ```

   > The Makefile targets default to `HOST=microban`. To operate the robot over the
   > secondary network, pass `HOST=microban-ext` (e.g. `make run HOST=microban-ext`),
   > or export it for the whole session: `export HOST=microban-ext`.

4. **Copy your SSH key** (recommended) so you are not prompted for a password on every
   command:
   ```bash
   ssh-keygen -t ed25519     # skip if you already have a key
   ssh-copy-id microban
   ```

5. **Push the code and install dependencies** on the Pi:
   ```bash
   make setup
   ```
   This rsyncs your local copy to the robot and runs `uv sync --frozen` there.

## Step 6: Run the Robot

Your Microban is ready! Place it on a stable surface (or hold it securely), then start
the control loop from your computer:

```bash
make run
```

On start the robot enables torque and ramps to its neutral pose, then runs the control
loop at 50 Hz attached to your terminal. Press `q` or run `make stop` to stop.

🎉 For the full set of controls — Makefile commands, keyboard and gamepad driving,
the available moves, and how to add your own — see the **[Usage Guide](usage.md)**.

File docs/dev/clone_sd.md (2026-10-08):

# Cloning the SD card

This produces the distributable `microban.img.xz`. Do the **depersonalization** and **imaging** steps every time you cut a new image.

## Depersonalize before each clone

Right before imaging, remove everything personal/unique so each user gets a clean,
private robot. Power off the Pi, insert the SD into your PC, then (adjust the mount
paths if needed):

```bash
R=/media/$USER/rootfs

# SSH host keys — regenerated on first boot by regen-ssh-host-keys.service
sudo rm -f "$R"/etc/ssh/ssh_host_*

# machine-id — regenerated on first boot; ensures unique DHCP identity / IP per robot
sudo truncate -s 0 "$R/etc/machine-id"

# cloud-init instance state — clears the "already configured" flag so the user's
# network-config (Wi-Fi) is actually applied on their first boot. Without this,
# cloud-init treats the image as already set up and IGNORES network-config edits, so
# the robot never joins the user's network. (Equivalent to `cloud-init clean` on the Pi.)
sudo rm -rf "$R"/var/lib/cloud/instances/* "$R"/var/lib/cloud/instance \
            "$R"/var/lib/cloud/sem/* "$R"/var/lib/cloud/data/*

# netcfg watcher stamp — records the sha256 of the last-applied network-config
# (see setup_rasp.md, microban-netcfg-reapply.service). If left behind, it still
# holds YOUR network's hash, so the first user's identical-looking config can be seen
# as "unchanged" and the Wi-Fi never gets re-applied. Always clear it here.
sudo rm -f "$R"/var/lib/microban/netcfg.sha256

# Your Wi-Fi credentials (any NetworkManager connection you created).
sudo rm -f "$R"/etc/NetworkManager/system-connections/*.nmconnection

# netplan's mirror of any NetworkManager Wi-Fi connection (e.g.
# /etc/netplan/90-NM-<uuid>.yaml). This retains the SSID and password in plaintext
# even after the .nmconnection file above is removed.
sudo rm -f "$R"/etc/netplan/90-NM-*.yaml

# Your SSH public key, shell history, caches and logs
sudo rm -f "$R/home/user/.ssh/authorized_keys"
sudo rm -f "$R/home/user/.bash_history"
sudo rm -f "$R"/var/cache/apt/archives/*.deb
sudo rm -rf "$R"/var/log/journal/* "$R"/var/log/*.log "$R"/var/log/*.gz
```

Reset the Wi-Fi config to placeholders so it does not ship with your network
credentials:
```bash
sudo tee /media/$USER/bootfs/network-config >/dev/null <<'EOF'
network:
  version: 2
  ethernets:
    eth0:
      dhcp4: true
      dhcp6: true
      optional: true
  wifis:
    wlan0:
      dhcp4: true
      regulatory-domain: "<YOUR_COUNTRY_CODE>"
      access-points:
        "<YOUR_WIFI_NAME>":
          password: "<YOUR_WIFI_PASSWORD>"
      optional: true
EOF
```

Also confirm the password is the documented default (`user` / `password`) and the
hostname is `microban`, so the image matches [the deployment guide](../deployment.md).

## Create and shrink the image

Go to gnome disks and create an image of the SD card.

Then shrink and compress it. The `-Z` flag compresses the shrunk image with `xz`
(turning a ~4 GB raw image into a few hundred MB), and `-a` runs the compression in
parallel across all CPU cores — much faster than the default single-threaded `xz`:
```
wget https://raw.githubusercontent.com/Drewsif/PiShrink/master/pishrink.sh
chmod +x pishrink.sh
sudo ./pishrink.sh -aZ ~/Documents/microban.img
```

This produces `~/Documents/microban.img.xz`. Check the final size with:
```
ls -lh ~/Documents/microban.img.xz
```

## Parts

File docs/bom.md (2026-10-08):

# Bill of Materials (BOM)

Here is a detailed Bill of Materials (BOM) for the project, including links to purchase each component and their approximate prices. Please note that prices may vary based on location and availability. You can source the components from your preferred suppliers, but beware that for electronic components using cheaper distributors may result in lower quality and reliability. 

Unlike the other components, the **[RPI Robot Hat](https://github.com/pollen-robotics/elec_RPI_Robot_HAT)** is not an off-the-shelf part: it is an open-source board that you need to have manufactured. Its design files are freely available on GitHub and can be ordered from any PCB fabrication service (e.g. JLCPCB, PCBWay, Aisler). The listed price is a rough estimate and will depend on the fab you choose and the quantity ordered. 

At the time of writing, **a Microban robot costs approximately $2,090** with this configuration (XC330-T288-T servos, 3S battery pack, and the added stereo camera -- the camera price is an estimate pending a firm quote from the supplier).

If you also include the configuration tools (Dynamixel U2D2 and U2D2 Power Hub), the total cost rises to approximately $2,145.

> [!WARNING]
> **Note regarding PCB Ordering with JLCPCB**
> 
> The default R33 resistor might currently be out of stock at JLCPCB, so double-check its presence during the preview step. If the default R33 is on shortage, you can easily swap it with another 150R 0402 resistor (e.g., part numbers `RT0402BRD07150RL` or `RCA02150RJLF`).
> 

## Robot Components

To build a complete Microban robot, you will need the following components:

| Component | Image | Quantity | Price | Link | Description / Notes |
| :--- | :---: | :---: | :--- | :--- | :--- |
| Battery Holder |  | 1 | ~$3.00 | [BC Robotics](https://bc-robotics.com/shop/3-x-18650-battery-holder/) | 3x18650 Battery Holder (11.1V nominal / 12.6V full charge). Photo shows the previous 2x18650 holder. |
| BMS |  | 1 | ~$10.83 | [eBay](https://www.ebay.com/itm/354994909729) | Battery Management System for 3x18650 batteries (12.6V 3S, with balance). Confirm the current rating covers your discharge needs before buying. |
| Switch |  | 1 | ~$5.00 | [Amazon](https://www.amazon.fr/gp/product/B0F32NVDHW/ref=ewc_pr_img_1?smid=A3PA4HG72LIUMJ&psc=1) | Power switch for the robot. |
| Charger |  | 1 | ~$10.00 | [Amazon](https://www.amazon.fr/gp/product/B0BWTK7SVN/ref=ox_sc_act_title_1?smid=A25R4KS2AL1P7J&psc=1) | Standard USB-C charger. |
| Batteries |  | 3 | ~$4.00 each | [Nkon](https://www.nkon.nl/fr/sony-murata-us18650-vtc6.html) | 18650 3.7V Lithium-ion Batteries (3S pack). Murata VTC6 are recommended but not mandatory. |
| Raspberry Pi Zero 2W |  | 1 | ~$15.00 | [Raspberry Pi](https://www.raspberrypi.com/products/raspberry-pi-zero-2-w/) | Microcontroller for the robot. |
| RPI Robot Hat |  | 1 | ~$30.00 | [GitHub](https://github.com/pollen-robotics/elec_RPI_Robot_HAT) | Open-source custom hat for the Raspberry Pi Zero 2W. The design files are available on GitHub and can be manufactured by any PCB fabrication service. |
| ELP-3DGS1200P01-H120 |  | 1 | ~$85 (estimate) | [ELP](https://www.elpcctv.com/elp-1200p-global-shutter-synchronous-dual-lens-usb-camera-module-no-distortion-112-degree-p-494.html) | Synchronized dual-lens (stereo) USB camera, 3200x1200 max resolution, nominal 112 degree horizontal FOV, ~59mm lens baseline measured from CAD. The ELP listing is quote-based; price is estimated from similar modules in the same product family. |
| 16GB+ micro SD card |  | 1 | ~$10.00 | [Amazon](https://www.amazon.fr/-/en/SanDisk-microSDHC-Adapter-Performance-SDSQUA4-032G-GN6MA/dp/B08GY9NYRM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) | Class 10 micro SD card of at least 16GB for OS and software. |
| Dynamixel XC330-T288-T |  | 21 | $89.90 each | [Robotis](https://en.robotis.com/shop_en/item.php?it_id=902-0171-000) | Metal-gear upgrade of the XL330-M288-T (same mounting footprint). Servomotor with 1 motor, 1 180mm cable, 10 M2x8 screws, 6 M2x6 screws. Photo shows the previous XL330-M288-T. |
| M2x6 STP39 Screws |  | 10 | ~$3 (depends on quantity) | [Screwerk](https://de.screwerk.com/fr/shop/detail/stp/STP390200060S.html) | Screws for the motor horns. Self-tapping screws for plastic. Complete the screws from motor kits. |
| Filament material |  | <1 | ~$10.00 | Depends on the 3D printer | To print the robot parts. Less than one roll. |
| 20x30x1mm POM shims |  | 4 | ~$2.50 for 20 | [AliExpress](https://fr.aliexpress.com/item/1005006482475865.html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) | POM washers used as plain bearings. Alternative to needle bearings for motors without idler horns. |
| 25x30x0.3mm Steel shims |  | 8 | ~$1.75 for 10 | [AliExpress](https://fr.aliexpress.com/item/1005001878233881.html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) | Parts on which the POM shim rests. |
| M2.5x6 Screws |  | 18 | ~$3 (depends on quantity) | [Screwerk](https://de.screwerk.com/fr/shop/detail/stm/STM320200060S.html) | Standard M2.5x6 screws to attach the idle horns to the motors. Any standard should work. |

**Important Note:** The total number of M2x6 screws contained in 21 motor kits is 126, while the number of M2x6 screws required for the assembly is still 124 (the 2 new neck roll/pitch joints use M2.5 screws, not the standard horn M2x6, so this requirement is unchanged from the original 19-servo design). With 21 motors you therefore already have a couple of spare M2x6 screws. I still personally recommend buying some additional M2x6 screws to avoid any issues during assembly. I also recommend buying M2.2x8 for the motor fixation, as the M2x8 screws provided with the motors may not fit perfectly, although they are usable. Check the [Optional Components](#optional-components) section for more details.

## Configuration Tools

In addition to the components that make up the robot, you will also need configuration tools to set up the Dynamixel motors:

| Component | Quantity | Price | Link | Description / Notes |
| :--- | :---: | :--- | :--- | :--- |
| Dynamixel U2D2 | 1 | $32.10 | [Robotis](https://en.robotis.com/shop_en/item.php?it_id=902-0132-000) | USB to Dynamixel adapter for motor configuration. |
| Dynamixel U2D2 Power Hub | 1 | $19.00 | [Robotis](https://en.robotis.com/shop_en/item.php?it_id=902-0145-001) | Power hub for U2D2. |
| 5V DC Power Supply | 1 | ~$5.00 | [AliExpress](https://fr.aliexpress.com/item/1005006681380264.html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) | 5V DC power supply for U2D2 Power Hub. Does not require a lot of current, it is only needed for the initial configuration. |

In case of building several robots, it is not necessary to buy several U2D2 sets, as they are only required for the initial configuration of the motors. 

## Optional Components

As discussed in the [Robot Components](#robot-components) section, I personally recommend replacing the provided M2x8 screws by M2.2x8 screws. For your information, the total amount of M2x6 self-tapping screws required for the assembly is 124, they are used to fix the horns to the parts. The total amount of M2x8 / M2.2x8 self-tapping screws required for the assembly is 66, they are used to fix the motors to the parts. Having extra screws can also be useful in case of loss.

The number of cables provided with the motors should be sufficient for the robot, but you may need additional cables in case of damage. 
It is also preferable to adjust the cable lengths to the minimum required for the robot to avoid cable entanglement. It is possible to only use off-the-shelf cables of size 50mm (6), 100mm (4), and 180mm (9), but due to the lack of availability, it is preferable to crimp your own cables. To do so, you can buy SEH-001T-P0.6 crimp pins and adjust 180mm cables to the required lengths. Detailed instructions on how to crimp your own cables will be provided in the Assembly Guide.

Finally, if you plan to use Microban intensively, you may want to consider having additional batteries and a charger to avoid downtime during charging. 

For all these reasons, here are some optional components you may want to consider:

| Component | Quantity | Price | Link | Description / Notes |
| :--- | :---: | :--- | :--- | :--- |
| Screws STP39 2x6 | 100 | ~$30 (depends on quantity) | [Screwerk](https://de.screwerk.com/fr/shop/detail/stp/STP390200060S.html) | Optional self-tapping screws for horn to part attachment. |
| Screws STP39 2.2x8 | 100 | ~$30 (depends on quantity) | [Screwerk](https://de.screwerk.com/fr/shop/detail/stp/STP390220080B.html) | Optional screws self-tapping for motor to part attachment. |
| Additional cables | 10 | $19.00 | [Robotis](https://en.robotis.com/shop_en/item.php?it_id=903-0249-000) | X3P cables for motors. Can be made with JST EHR-3 connectors. |
| SEH-001T-P0.6 | 100 | ~$5 | [AliExpress](https://fr.aliexpress.com/item/1005005433081646.html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) | JST EH crimp pin of size 2.50mm in roll. Compatible with JST EHR-3 connectors. |
| Crimp tool | 1 | ~$12 | [AliExpress](https://fr.aliexpress.com/item/1005003429462091.html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) | Crimping tool. Should contain a 1.9mm die for the SEH-001T-P0.6 crimp pin. |
| Additional batteries | 1 | ~$4 | [Nkon](https://www.nkon.nl/fr/sony-murata-us18650-vtc6.html) | 18650 3.7V Lithium-ion Batteries. Murata VTC6 are recommended but not mandatory. |
| 18650 Li-ion charger | 1 | ~$15 | [RS](https://fr.rs-online.com/web/p/chargeurs-de-batterie/1466770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) | Charger for 18650 Li-ion batteries. |

---

Once you have all the components, you can proceed to print the parts. Follow the [Printing Guide](printing.md) for detailed instructions.

If you already have the parts printed and the components purchased, you can directly proceed to the assembly of the robot by following the [Assembly Guide](assembly.md).

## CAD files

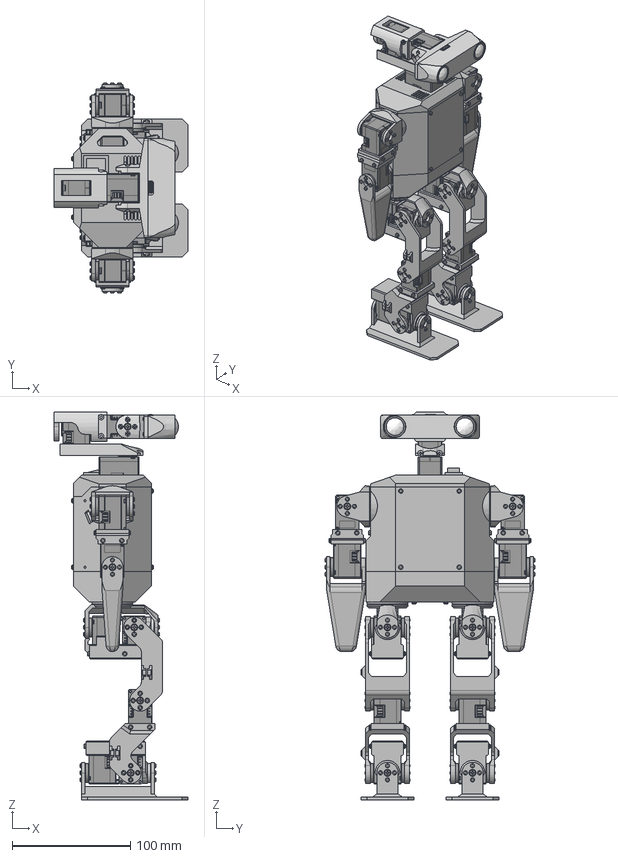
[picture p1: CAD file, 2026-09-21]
cad/microban.step
113.5 x 177.8 x 328.5 mm
DC15_A01_HORN_IDLE2_DUMMY x 6
STP39_1 x 66
DC15_A01_IDLE_CAP_DUMMY x 8
BTS2_M2_6X8 x 8
XL330 x 8
spacer x 4
XL330_without_horn x 13
ankle_dbl_block x 2
STP39 x 16
foot x 2
STP39_2 x 104
hip x 2
radius x 2
shoulder x 2
hip_dbl_block
humerus x 2
tibia
hip_dbl_block_1
tibia_1
arm_bearing_support x 2
raspberry_pi_zero_2W
steel_shim x 8
pelvis
trunk_top
washer x 4
battery
charger
pom_shim x 4
switch
BMS
chest
hat
femur
femur_1
base
ic
lens
pcb
usb-type-c

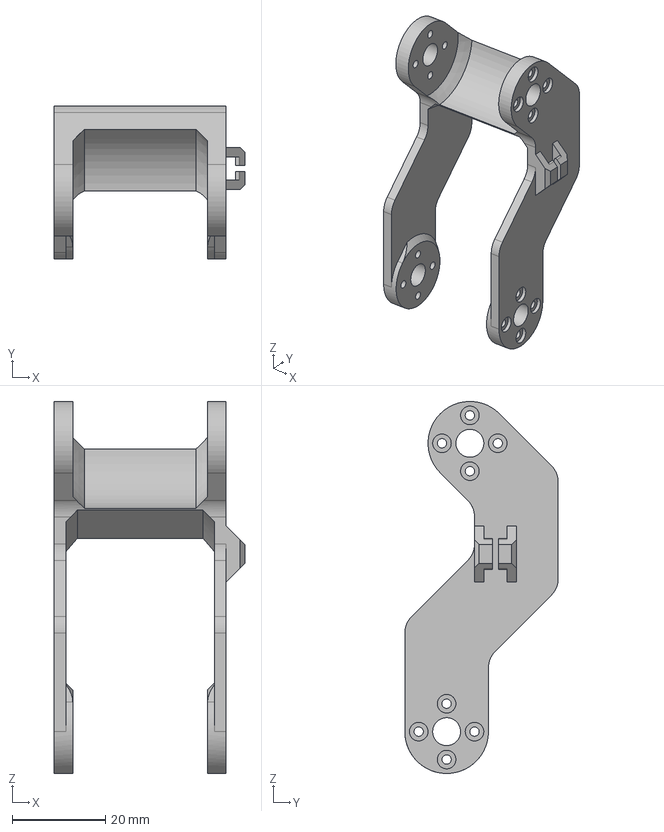
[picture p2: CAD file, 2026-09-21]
cad/step/femur_left.step
41.0 x 33.0 x 80.0 mm

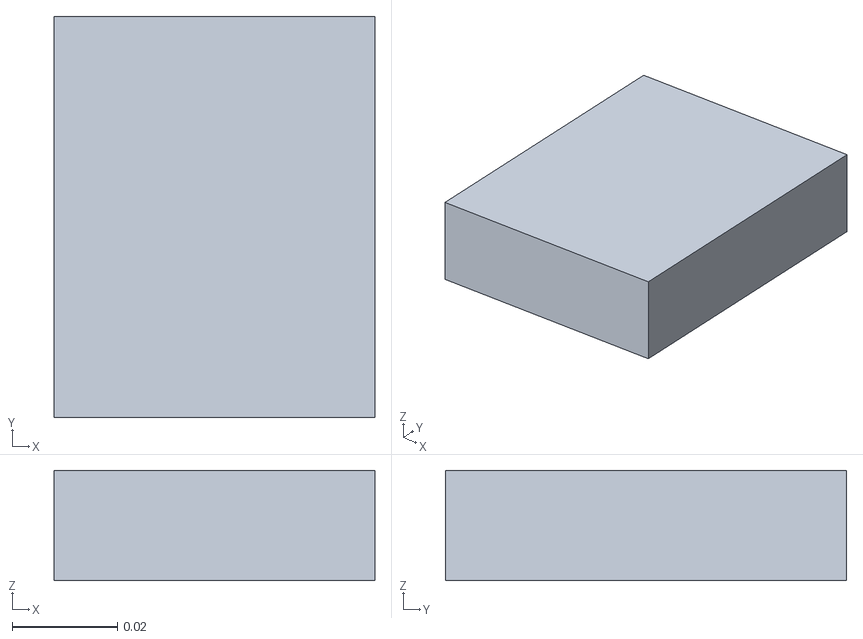
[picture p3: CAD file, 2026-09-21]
src/model/mjcf/assets/battery.stl
0.061 x 0.0763 x 0.021

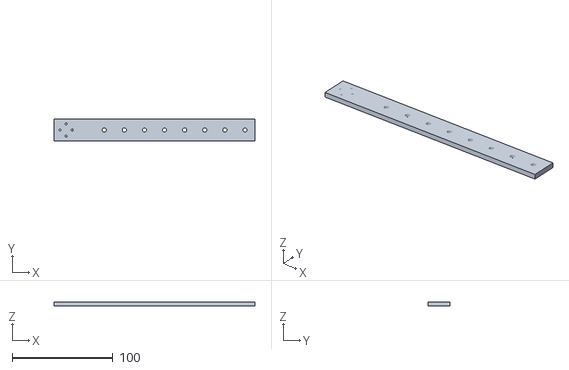
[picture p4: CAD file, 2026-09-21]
tools/actuator_id/pendulum_arm.stl
200.0 x 22.0 x 4.00

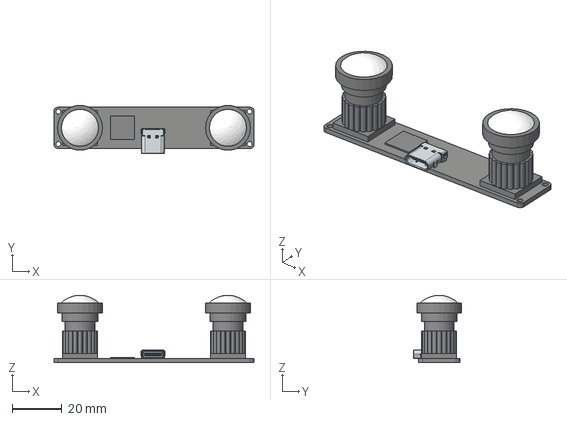
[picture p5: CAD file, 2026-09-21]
cad/ELP-3DGS1200P01-H120.step
80.0 x 19.2 x 27.0 mm

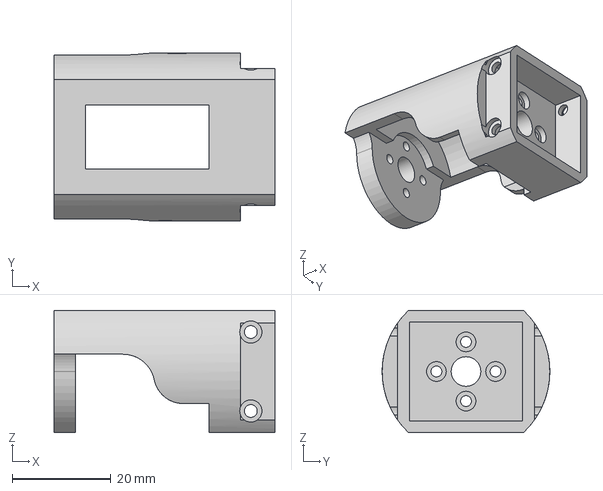
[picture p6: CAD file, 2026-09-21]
cad/step/roll_pitch_link.step
44.8 x 34.0 x 24.8 mm

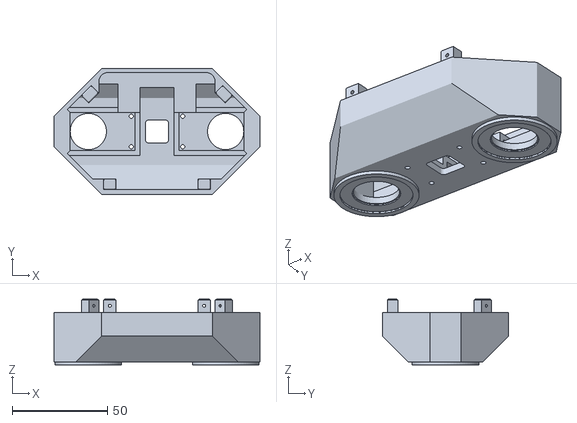
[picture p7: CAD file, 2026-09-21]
src/model/mjcf/assets/pelvis__configuration_right.stl
108.0 x 66.0 x 34.5

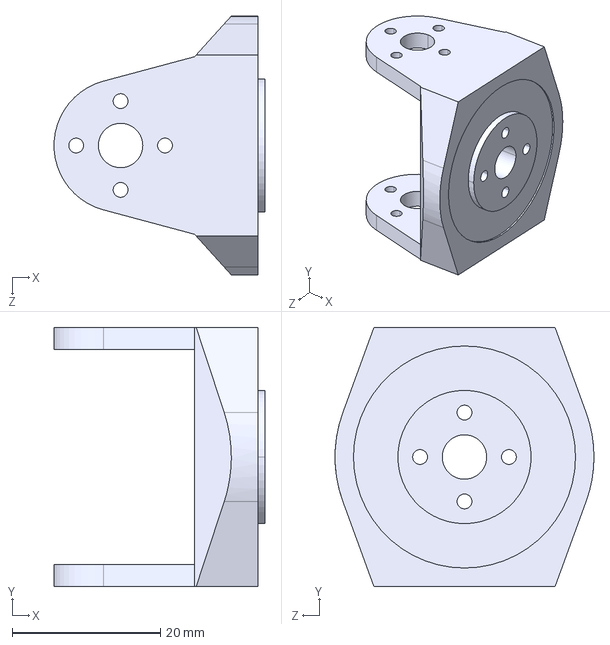
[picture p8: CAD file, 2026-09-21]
cad/step/shoulder.step
28.5 x 35.0 x 35.0 mm

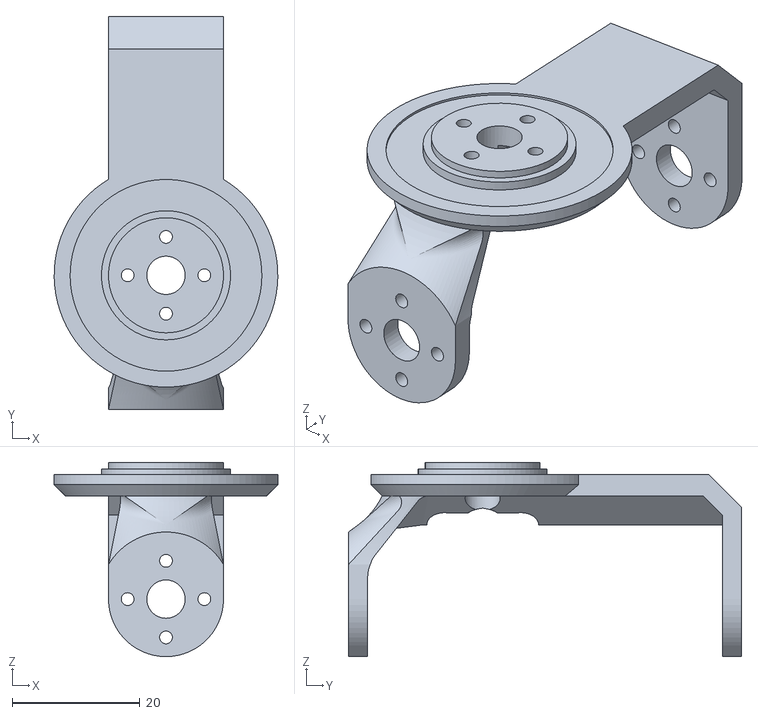
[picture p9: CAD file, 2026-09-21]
src/model/mjcf/assets/hip__configuration_right.stl
35.0 x 61.5 x 30.4

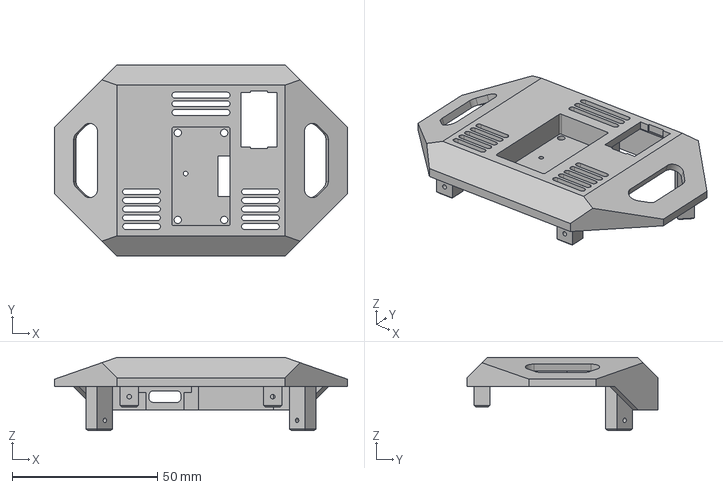
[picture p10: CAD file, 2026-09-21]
cad/step/trunk_top.step
101.0 x 66.0 x 25.2 mm

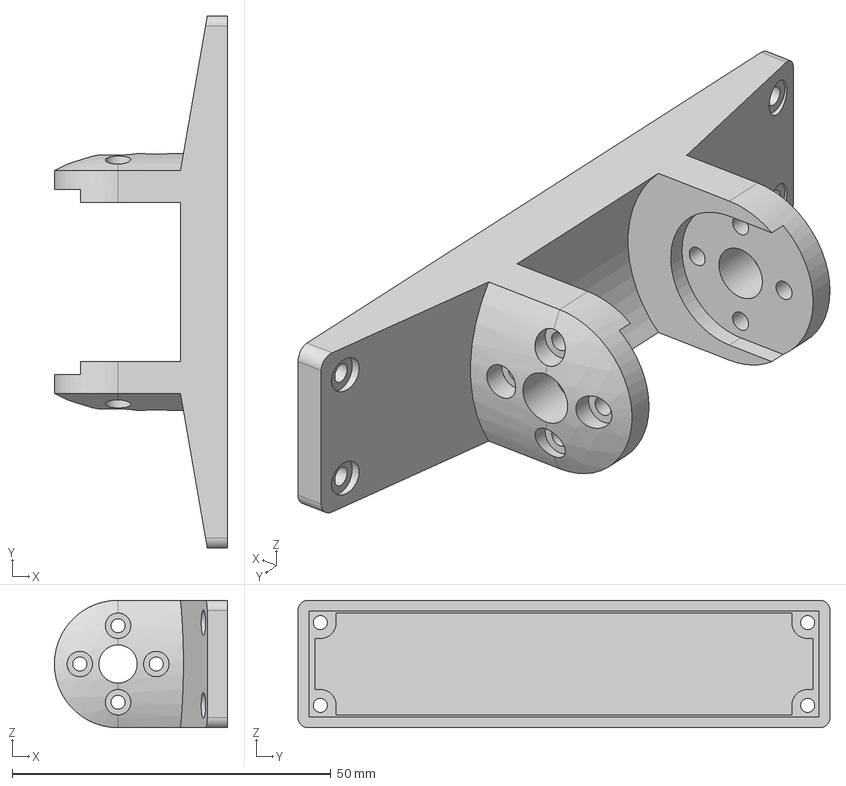
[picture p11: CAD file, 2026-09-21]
cad/step/pitch_servo_cradle.step
27.2 x 83.5 x 20.0 mm

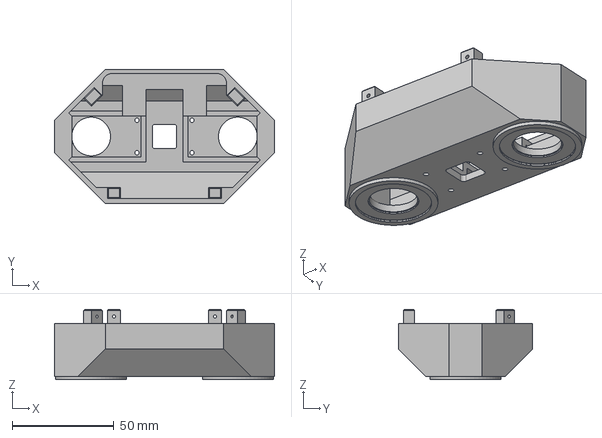
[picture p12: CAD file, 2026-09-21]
cad/step/pelvis.step
108.0 x 66.0 x 34.5 mm

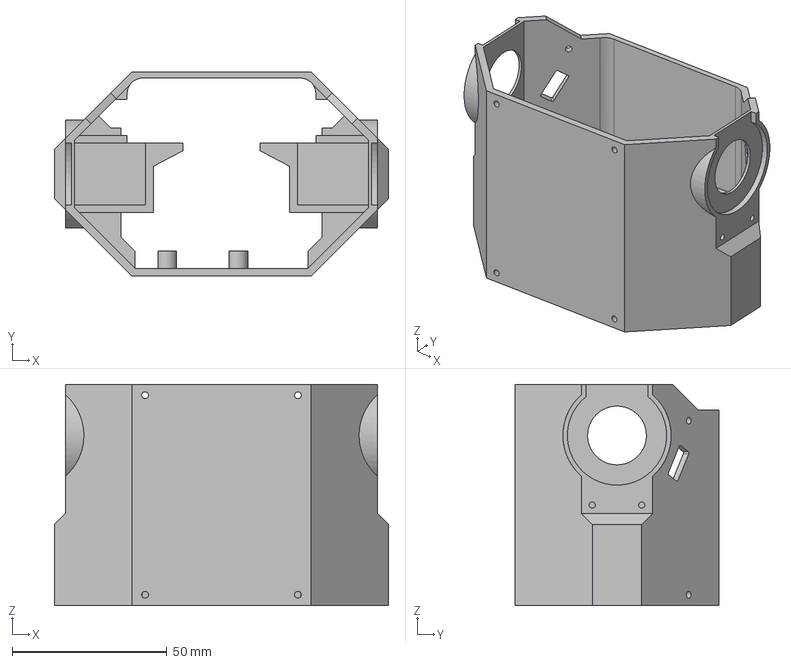
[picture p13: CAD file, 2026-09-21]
cad/step/chest.step
108.0 x 66.0 x 71.5 mm

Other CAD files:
cad/step/femur_right.step
src/model/mjcf/assets/elp-3dgs1200p01-h120.stl
src/model/mjcf/assets/femur__configuration_left.stl
src/model/mjcf/assets/femur__configuration_right.stl
src/model/mjcf/assets/pitch_servo_cradle.stl
cad/ELP-3DGS1200P01-H120.sldprt
cad/microban.f3d
cad/microban.f3z
cad/step/camera_cover.step
cad/step/foot.step
cad/step/hip.step
cad/step/m2.5spacer.step
cad/step/roll_servo_cradle.step
cad/step/washer.step
cad/stl/camera_cover.stl
cad/stl/chest.stl
cad/stl/femur_left.stl
cad/stl/femur_right.stl
cad/stl/foot.stl
cad/stl/pitch_servo_cradle.stl
cad/stl/roll_pitch_link.stl
cad/stl/roll_servo_cradle.stl
cad/stl/trunk_top.stl
src/model/mjcf/assets/camera_cover.stl
src/model/mjcf/assets/foot__configuration_right.stl
src/model/mjcf/assets/roll_pitch_link.stl
src/model/mjcf/assets/roll_servo_cradle.stl

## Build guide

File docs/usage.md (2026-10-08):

# Using Microban

This guide covers day-to-day operation once the robot has been set up (see the
[Deployment Guide](deployment.md)). You drive the robot from your computer with the
`Makefile`, which talks to the Pi over SSH. You can use the keyboard or a Bluetooth 
gamepad to control it, and optionally run it

> [!IMPORTANT]
> Always run `make shutdown` before cutting power to the robot. This is **not**
> automatic — powering off the Pi without a clean shutdown can corrupt the SD card.
> Wait 10-15 s after the command before flipping the power switch off, to give the
> Pi time to actually halt.

## Makefile commands

Run these from the repository root on your computer. They target the host `microban`
by default; add `HOST=microban-ext` to operate over the secondary network (see the
[Deployment Guide](deployment.md)).

| Command | What it does |
| :--- | :--- |
| `make run` | Sync the code and start the control loop on the robot (50 Hz). Stays attached to your terminal for live control. |
| `make stop` | Stop the control loop and disable torque on all motors. |
| `make shutdown` | Power off the Pi cleanly. |
| `make setup` | Sync the code and (re)install dependencies on the robot (`uv sync --frozen`). Run after changing dependencies. |
| `make sync` | Sync your local copy to the robot without touching dependencies. |
| `make imu` | Stream the robot's IMU/gyro readings to your terminal. |
| `make voltage` | Read the voltage of all motors. |
| `make voltage ID=<id>` | Read the voltage of motor `<id>`. |
| `make sim` | Run the MuJoCo simulation locally (no robot needed). |
| `make viewer` | Open the MuJoCo viewer locally (no robot needed). |
| `make teleop-run` | Run the robot with the PICO UDP input from the `microban_teleop` PC bridge (see [Teleoperation](teleop.md)). |
| `make teleop-sim` | Run MuJoCo with the same UDP input, for testing before hardware. |
| `make camera-stream-enable` | Install/start the optional stereo MJPEG service after the camera is connected. |

## Running the robot

1. Place the robot on a stable surface, or hold it securely — on start it enables
   torque and ramps to its neutral pose.
2. `make run` — the control loop starts at 50 Hz and stays attached to your terminal. Some latency is expected due to the SSH connection.
3. Toggle moves and drive the robot (see below).
4. `make stop` (or press `q`) to stop; `make shutdown` to power off.

## Controlling with the keyboard

| Key | Action |
| :--- | :--- |
| `v` | toggle the **walk** move |
| `h` | toggle the **head** move |
| `s` | toggle the **squat** move |
| arrows | `vx` (up/down), `vtheta` (left/right) |
| `x` | reset velocity to zero |
| `i` | toggle the IMU/gyro display |
| `q` | stop the control loop |

## Controlling with a gamepad

A Bluetooth Xbox controller can be used instead of the keyboard. The detailed explanation of the gamepad usage is in [Gamepad Guide](gamepad.md). 

Using a gamepad allows to drive the robot through two different modes: with a terminal (SSH) or fully headless (no SSH, no terminal). The second mode is particularly useful for demonstration purposes, due to the fact that it allows to drive the robot without any computer connected to it.

## Moves

Moves are toggled independently and run on top of the neutral pose:

- **Walk** (`v` / gamepad **X**) — the move that owns the legs. With the keyboard or a
  gamepad it holds the current pose; walking runs from the PICO controller
  ([Teleoperation](teleop.md)) or the GC300 runtime ([GC300](gc300.md)).
- **Head** (`h`) — oscillates the head.
- **Squat** (`s`) — squat motion computed with inverse kinematics.

### Velocity command

Every input source emits a **normalized** command in `[-1, 1]` per axis; the scheduler
maps it to physical limits with `scale_velocity()`, so the behavior is identical for
keyboard, gamepad and sim. Defaults (in [constants.py](../src/constants.py)):

| Axis | Max |
| :--- | :--- |
| `vx` (forward) | +0.7 |
| `vx` (backward) | -0.5 |
| `vy` (lateral) | ±0.3 |
| `vtheta` (turning in place, `vx = vy = 0`) | ±3.0 |
| `vtheta` (while translating) | ±1.5 |

## Real-robot joint offsets

If one robot holds a joint slightly off from where the policies expect it (a servo
horn mounted slightly off, a slightly bent bracket, a robot that wants its ankles
pitched forward a little), correct it with the per-joint table
`HARDWARE_JOINT_OFFSET_DEG` in [constants.py](../src/constants.py). It lists all 21
joints and every value is `0.0` by default.

- Units: degrees of the **logical** joint coordinate (the one used by the policies,
  training, `NEUTRAL_POSE` and the observations; before `MOTOR_SIGN`). A positive value
  moves the real joint further in that joint's positive direction.
- Convention: `servo command = MOTOR_SIGN * (logical target + offset)` and
  `logical measurement = MOTOR_SIGN * servo reading - offset`.
- Scope: applied only inside `RobotController` (the real servo bus), on every goal
  write and every position read. Every move (walk, PICO tracking, get-up, the A /
  policy-off neutral pose, arms, head and neck) and every input source (keyboard,
  gamepad, GC300, PICO) gets it automatically, and the policies keep observing
  training coordinates. Velocities and currents are unchanged. MuJoCo / placo
  simulation (`make sim`, `make viewer`) and training ignore it.
- Measuring: with all offsets `0.0`, hold the joint at a known true angle (in the
  logical coordinate) and read its logical position `m` from the runtime (it already
  includes `MOTOR_SIGN`). Then `offset = m - true angle`, converted to degrees. Getting
  the sign wrong doubles the error instead of removing it.
- Limit: each value must be finite and at most `HARDWARE_JOINT_OFFSET_MAX_RAD`
  (0.2 rad, about 11.5 deg); otherwise the runtime refuses to start. Nonzero values are
  printed once when the runtime starts (`Hardware joint offsets (...)`). Offsets are
  calibration trims; they do not keep goals in range.
- Servo range: policies have no software clip. Every policy target is
  `clip(HOME + raw * 1.0, -pi, +pi)`, the servo's one-turn goal range. After sign and
  offset, `RobotController` saturates every servo goal into
  `[SERVO_GOAL_MIN_RAD, SERVO_GOAL_MAX_RAD] = [-pi, pi - 2*pi/4096]` rad, which is raw
  0..4095 in XC330 Position Control mode (rustypot: `raw = (rad + pi) * 4096 / (2*pi)`).
  An in-range goal is sent unchanged. A goal past an edge is sent as that edge, and the
  cached goal becomes the edge mapped back to the logical coordinate. At startup the
  runtime reads every servo's Operating Mode and Min/Max Position Limit: a servo that
  answers with a mode other than Position Control (3), or with fewer than two raw values
  between its limits, stops startup with an error naming the joints and every servo's
  torque OFF; a servo with narrower limits (read the same twice) gets them as its own
  goal range (intersected with 0..4095) and is printed once (`Servo position limits: ...
  raw [min, max] -> logical [lo, hi] rad`, plus a WARNING if its neutral pose is outside);
  a servo that does not answer keeps the full range with one warning line and is read
  again when it first answers a position read (a non-position mode found then stops the
  runtime the same way).

Example: to pitch both feet 1 degree forward, set
`"left_ankle_pitch": -1.0` and `"right_ankle_pitch": -1.0`, then `make sync` and restart
the runtime.

## Developing: adding your own moves

Each behavior is a subclass of `Move` ([src/moves/move.py](../src/moves/move.py)) with
a simple lifecycle driven by the scheduler:

- `preload()` — optional, called once before the loop starts (load heavy resources).
- `on_start(obs, command)` — called each tick while *starting*; set
  `self.state = MoveState.ACTIVE` when ready (e.g. after ramping in).
- `step(obs, command)` — called each tick while *active*; write your target joint
  angles into `command.target_angles`.
- `on_stop(obs, command)` — called each tick while *stopping*; set
  `self.state = MoveState.INACTIVE` when done (e.g. after ramping back to neutral).

To add a move:

1. Create a new file in [src/moves/](../src/moves/) with a class subclassing `Move`.
   Use [rotate_head.py](../src/moves/rotate_head.py) (a simple oscillation) or
   [squat.py](../src/moves/squat.py) (inverse kinematics with placo) as a template.
2. Register it in [src/main.py](../src/main.py): add it to the `moves` dict passed to
   the `Scheduler`, and add a trigger — a key in `MOVE_KEYS` (keyboard) and/or a button
   in `GAMEPAD_BUTTON_MOVES` (gamepad).
3. In `step()`, read the robot state from `obs.robot_state` (motor positions and
   velocities, IMU gyro, projected gravity) and write your targets into
   `command.target_angles`.

### Training your own walk (or other RL) policies

The walk move runs an ONNX policy trained in simulation. 

PICO 4 Ultra network control is documented in [Teleoperation](teleop.md). The
left-trigger-held PICO policy and the contract, installation and validation of
every learned policy are documented in [learned policies](policies.md).
You can train your own walking — or other learned skills — and drop the resulting `.onnx` file into [src/agents/](../src/agents/) to use it on the robot. Check the repository [MarcDcls/mjlab_microban](https://github.com/MarcDcls/mjlab_microban) for the training pipeline. 

If you achieve some interesting results, don't hesitate to make a pull request to the repository as it is also a community-driven project!

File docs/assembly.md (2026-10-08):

# Assembly Guide

This guide provides detailed instructions on how to assemble the parts for the Microban robot. Printing the parts and buying the necessary components are prequisites for this guide, so please refer to the [Printing Guide](printing.md) and the [BOM](bom.md) before starting the assembly process. 

At any point during the assembly, you can refer to the [Onshape assembly](https://cad.onshape.com/documents/d424992a192a8ce34ffce163/v/7de3e6e40f0e1185d169e6d9/e/b34620a03cc3a684006c5867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) to see how the parts fit together.

The steps to assemble the robot are as follows:
1. [Motor Setup](#1-motor-setup): Configure the motors using the Dynamixel Wizard software.
2. [Cable Setup](#2-cable-setup): Prepare all the cables necessary for the assembly. 
3. [Leg Assembly](#3-leg-assembly): Assemble the legs of the robot.
4. [Torso Assembly](#4-torso-assembly): Assemble the torso and arms of the robot.
5. [Electronics](#5-electronics): Assemble the top of the trunk, build the battery module, and connect the electronics.
6. [Final Assembly](#6-final-assembly): Assemble all the parts together to complete the robot.

---

## 1. Motor Setup

The first step in the assembly process is to set up the motors. I highly recommend writing the motor IDs directly on them to avoid mixing them up during configuration and assembly. The following table lists the motor names and their corresponding IDs:

| Motor Name | ID |
|---|----|
| Left Hip Yaw | 11 |
| Left Hip Roll | 12 |
| Left Hip Pitch | 13 |
| Left Knee | 14 |
| Left Ankle Pitch | 15 |
| Left Ankle Roll | 16 |
| Right Hip Yaw | 21 |
| Right Hip Roll | 22 |
| Right Hip Pitch | 23 |
| Right Knee | 24 |
| Right Ankle Pitch | 25 |
| Right Ankle Roll | 26 |
| Left Shoulder Pitch | 31 |
| Left Shoulder Roll | 32 |
| Left Elbow | 33 |
| Right Shoulder Pitch | 41 |
| Right Shoulder Roll | 42 |
| Right Elbow | 43 |
| Head | 51 |
| Neck Roll | 52 |
| Neck Pitch | 53 |

To configure all the motors, connect one motor at a time to your PC using the U2D2 kit as presented in the image below. 



<br>
<br>

Then, launch [Dynamixel Wizard](https://emanual.robotis.com/docs/en/software/dynamixel/dynamixel_wizard2/). If your motor is not new, perform a factory reset by clicking on the "Recovery" button, selecting the matching model (XL-330-288 for the legacy XL330-M288-T, or the closest XC330-T288-T entry shown in the Recovery dropdown) and following the instructions. 

In the "Option" tab, select "Protocol 2.0", "57600 bps" as the baud rate, and verify that the correct COM port is selected. Then, click on the "Scan" button to detect the motor. Once the motor is detected, you can set the following parameters (and click on the "Save" button to save the settings):
- ID: the ID of the motor as listed in the table above
- Baud Rate: 3 (1Mbps)
- Return Delay Time: 0
- PWM Slope: 255 (no slope)
- Shutdown: 52 (Removing "Bit 0 Input voltage error")

Once the parameters are set, you can disconnect the motor and move on to the next one. If you want to check the motors at the end, you can connect them together as their IDs are set. You will need to change the baud rate of the scan to 1Mbps as it as been changed during the configuration. 

---

## 2. Cable Setup

The Dynamixel X-series motors used in the Microban robot are daisy-chained, which means that the motors are connected in series. This allows to limit the number of cables that need to be routed through the robot. The only exception is near the board, where the first cables are split to connect to several links. The following diagram shows how the motors are connected to each other and to the board, and what cable lengths are used for each connection. 

routing

### 2.1 Splitter Cable

To create the 1-to-2 splitter cable, you can cut 2 cables of 180mm to obtain 3 half-cables of approximately 50mm (you don't need more length than that). Then, you can solder 2 of them to the 3rd one. Be careful to solder together the same wires, as an incorrect connection can damage permanently the motors. Do not forget to insulate the soldered connections with heat shrink tubing. 

To do the 1-to-3 splitter cable, the process is the same, but one of the 3 outgoing cables should be longer than the other two to allow for the robot opening from the top. So you should cut 2 cables of 180mm into 3 half-cables of approximately 50mm and one half-cable of approximately 120-130mm. 

The following images shows how the splitter cable should look like.



### 2.2 Reducing Cable Length

To reduce the length of the 180mm cables, you can cut them to the desired length and solder the ends back together, but it can lead to a weak connection and communication issues. A better solution is to re-crimp the cables to the desired length. To do this, you will need a crimping tool, JST EH crimp terminals, and optionally a wire stripper. You can check the [BOM](bom.md) for references.



<br>
<br>

First, cut the cable to the desired length. The end cut to the correct length should be stripped to expose the wires on 2mm, not more. While crimping the terminals, the first crimp will be done on the plastic part of the terminal to hold the wire in place, and the second crimp will be done on the metal part of the terminal to make the electrical connection. The details of the crimping process are presented in this [video](https://youtu.be/2hUjM0x_yfw).

<p align="center">
  
  
</p>

Once the 3 end terminals are crimped, you need to retrieve the plastic housing from the second half of the cable. You can do this by rising the plastic stops on the housing with a small screwdriver and pulling the housing out. If you have trouble with this step, here is another [video](https://youtu.be/mWsNwO4s6kE) showing how to do it. 

Finally, you can insert the 3 crimped terminals into the plastic housing. The order of the wires is important, so make sure to insert them in their corresponding position. Here is a last [video](https://youtu.be/w1A9wdLn3Ro) showing how to insert the terminals into the housing.

--- 

## 3. Leg Assembly

The objective of this section is to assemble the legs of the robot and fix them to the pelvis. 

<p align="center">
  
</p>

For the assembly, you should refer to the [Onshape assembly](https://cad.onshape.com/documents/d424992a192a8ce34ffce163/v/7de3e6e40f0e1185d169e6d9/e/b34620a03cc3a684006c5867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) to see how the parts fit together. Nevertheless, some parts of the assembly require specific instructions and are detailed in the following sub-sections.

### 3.1 Double-Motor Blocks

For the double-motor blocks used in the ankle and hip joints of the robot, you should pay attention to the cable routing, as the motors are very close to each other. Specifically, the cable connected to the bus between the two motors should be plugged before sliding the motors into the double-motor block. It concerns the cable relying the two motors, as well as the cable connecting the double-motor block to the next motor in the chain. The following images show you the assembly process on a right ankle double-motor block. 

Cable routing before sliding the motors into the double-motor block (do not forget the spacer):

<p align="center">
  
</p>

Result after sliding the motors into the double-motor block:

<p align="center">
  
  
</p>

### 3.2 Cable Routing 

For the cable lengths, refers to the [Cable Setup](#2-cable-setup) section. You should use the cable sockets on the tibia, femur and hip double-motor blocks to route the cables through the robot. 
For the tibia and femur routing, you can check the first image of the section. For the hip double-motor block, you can check the image below. 

<p align="center">
  
</p>

### 3.3 Feet Adhesion

To increase the adhesion of the feet to the ground, you can add an optional layer of rubber on the bottom of the feet. You can use a rubber sheet or cut a piece of an old cycling tire. 

<p align="center">
  
</p>

---

## 4. Torso Assembly

The objective of this section is to assemble the torso of the robot. 

<p align="center">
  
</p>

For the assembly, you should refer to the [Onshape assembly](https://cad.onshape.com/documents/d424992a192a8ce34ffce163/v/7de3e6e40f0e1185d169e6d9/e/b34620a03cc3a684006c5867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) to see how the parts fit together. 

Once the torso is assembled, you can fix it to the pelvis and connect the splitter cables to the hip yaw motors, shoulder pitch motors, and the RPI Robot Hat.

<p align="center">
  
</p>

---

## 5. Electronics

The objective of this section is to assemble the electronics of the robot, including the battery module and the trunk top. 

The following schematic shows how the electronics are connected together. The battery module is composed of a 3S 18650 battery holder and a BMS board. It is connected to the trunk top with a xt30 connector. The trunk top contains the USB-C charger and the switch powering on the Raspberry Pi. The routing allows to charge the battery independently of the power state of the robot. The alimentation of the Raspberry Pi is done through one of the 2 JST EHR-4 connectors on the RPI Robot Hat. 

microban_elec

### 5.1 Battery Module

> **Note:** The steps below were written for the original 2S BMS. The pack is now 3S; a 3S BMS typically has 2 balance-tap wires (around 4.2V and 8.4V) instead of 1, in addition to the main pack +/- leads. Verify the exact pinout against the datasheet of whichever 3S BMS you actually buy -- do not assume the steps below map 1:1.

To assemble the battery module, first connect the 4.2V pin of the BMS to the metal contact on the battery holder, located on the side opposite the red (8.4V) and black (0V) wires. To make this easier, you can melt a small hole in the holder using your soldering iron to reach and solder the wire to the contact. Next, solder the positive (+) and negative (-) wires from the BMS to the XT30 connector. Once the wiring is complete, secure the BMS to the back of the battery holder using double-sided tape. Finally, apply hot glue to insulate all the connections and prevent any short circuits. The pictures below show the fully assembled battery module.

<p align="center">
  
  
</p>

### 5.2 Trunk Top

First, insert the switch into the trunk top. Using pliers, carefully fold its pins down to free up some vertical space.

Next, prepare the JST EHR-4 power cable for the RPI Robot Hat. Cut a Dynamixel cable to a length of approximately 150mm and remove the two unused wires. Refer to the picture below to see which wires to keep.

<p align="center">
  
</p>

To wire the components, start by soldering the USB-C charger to the XT30 connector, which will be used to connect the battery module. Next, wire the switch by soldering the charger's **BAT** pin to one of its terminals, and the **VIN** wire of the JST EHR-4 cable to the other. Finally, complete the circuit by soldering the **GND** wire of the JST EHR-4 cable directly to the **GND** pin of the USB-C charger. 

The picture below shows the result of the wiring process.

<p align="center">
  
</p>

*Important:* Because the trunk top is a printed plastic part (sensitive to heat), make sure to solder the USB-C charger module before mounting it to the plastic part. Also, once the wiring is complete, you should isolate the connections with hot glue to prevent any short circuits.

## 6. Final Assembly

To finalize the assembly of the robot, you just have to slide the battery module into the trunk, connect its XT30 connector to the trunk top, connect the JST EHR-4 cable to the RPI Robot Hat, and close the trunk with the trunk top. 

<p align="center">
  
  
</p>

<p align="center">
  WhatsApp Image 2026-06-25 at 18 08 36
</p>

If you have followed all the steps of this guide, your robot should be fully assembled and ready to be powered on. You can now proceed to the [Deployment Guide](deployment.md) to deploy the software on the Raspberry Pi and start controlling your Microban robot!

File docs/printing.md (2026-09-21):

# Printing Guide

This guide provides detailed instructions on how to print the parts for the Microban robot. It covers recommended settings, orientations, and tips to ensure successful prints. To see the full assembly of the parts, you can refer to the [Onshape assembly](https://cad.onshape.com/documents/d424992a192a8ce34ffce163/v/7de3e6e40f0e1185d169e6d9/e/b34620a03cc3a684006c5867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).

## Recommended Settings

The parts are available in the `cad/stl/` directory of this repository, and they are designed to be printed using a standard desktop 3D printer with PETG-CF (carbon-fiber-filled PETG) filament, 0.12mm layer height, and 100% infill. PETG-CF is abrasive, so use a hardened steel (or similarly wear-resistant) nozzle rather than plain brass. The next table summarizes the number of parts to print for each component of the robot. Please note that some parts may require specific orientations for printing, please refer to the [Part Orientation](#part-orientation) section for more details.

| Part | Quantity | Image | Description / Notes |
| :--- | :---: | :--- | :--- |
| foot.stl | 2 |  | Feet of the robot. |
| tibia_left.stl | 1 |  | Left tibia of the robot. Asymmetric to ensure proper cable routing. |
| tibia_right.stl | 1 |  | Right tibia of the robot. Asymmetric to ensure proper cable routing. |
| femur_left.stl | 1 |  | Left femur of the robot. Asymmetric to ensure proper cable routing. |
| femur_right.stl | 1 |  | Right femur of the robot. Asymmetric to ensure proper cable routing. |
| hip.stl | 2 |  | Hips of the robot. |
| ankle_dbl_block.stl | 2 |  | Double motor blocks for the ankle joint. |
| hip_dbl_block_left.stl | 1 |  | Left double-motor block for the hip joint. Asymmetric to ensure proper cable routing. |
| hip_dbl_block_right.stl | 1 |  | Right double-motor block for the hip joint. Asymmetric to ensure proper cable routing. |
| spacer.stl | 4 |  | Cable clearance spacers for ankle and hip double-motor blocks. |
| pelvis.stl | 1 |  | Pelvis of the robot. Lower part of the torso. |
| chest.stl | 1 |  | Chest of the robot. Middle part of the torso. |
| trunk_top.stl | 1 |  | Top part of the torso. |
| head.stl | 1 |  | The head of the robot. Currently just cosmetic, but can be modified to include sensors or cameras. |
| arm_bearing_support.stl | 2 |  | Supports for the shoulder shims. Printed separately from the chest to allow for better orientation and print quality. |
| shoulder.stl | 2 |  | Shoulder joints of the robot. |
| humerus.stl | 2 |  | Upper arms of the robot. |
| radius.stl | 2 |  | Lower arms of the robot. |
| idle_horn.stl | 4 |  | Idle horn for XL330 motors. This part can be bought from Robotis, but printing it does not affect the quality and is cheaper. |
| idle_cap.stl | 6 |  | Idle cap to fit the idle horn. This part can be bought from Robotis, but printing it does not affect the quality and is cheaper. Two of the caps are designed to fit the forearm parts (radius). |
| board_spacer.stl | 4 |  | Unthreaded spacer to place between the Raspberry Pi and the RPI Robot hat. | 

## Part Orientation 

The parts that support the plain bearings (POM washers sandwiched between steel shims) should be printed in a specific orientation to ensure proper fit and surface finish. These orientations can increase the required support material, but they are necessary to ensure that the bearings fit correctly and that the parts function as intended. These parts are: 
- `hip.stl`
- `pelvis.stl`  
- `arm_bearing_support.stl`
- `shoulder.stl`

The following parts also require specific orientations to ensure proper fit and alignment with the motors:
- `idle_horn.stl`
- `idle_cap.stl`
- `radius.stl`

The following images show the recommended orientations for the parts listed above.



<br>
<br>

For all the other parts, the orientation is quite straightforward, and they can be printed without the need of support material for a lot of them.

---

Once you have all the parts, if you already purchased the necessary components listed in the [BOM](bom.md), you can proceed to assemble the robot by following the [Assembly Guide](assembly.md).

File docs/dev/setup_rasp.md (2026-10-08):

## Raspberry Pi setup

- Download the Raspberry Pi imager: https://www.raspberrypi.com/software/
- Plug your sd card in your computer
- Run it as sudo:

```
sudo Downloads/imager_[...].AppImage
```

- Select Raspberry Pi Zero 2 W
- Select Raspberry Pi OS (other)
- Select Raspberry Pi OS Lite (64-bit)
- Select your SD card
- Name it "microban"
- Select your timezone
- Set a username and a password
- Set the SSID and password of your local network (2.4 GHz)
- Activate SSH with password authentification
- Write

Once it's done, eject the SD card and plug it in your robot. It should boot and connect to your wifi. The first time it boots, it will take a while to expand the filesystem and install updates, so be patient and don't switch it off.

## Connecting to the Pi from your computer

To connect to your Raspberry Pi from your computer, it needs to be on the same network. 
Once on the same network, you can find the IP address of your Raspberry Pi by running:
```
ping microban.local
```

You should see a response looking like this:
```
64 bytes from 192.168.XXX.XXX: icmp_seq=1 ttl=64 time=100 ms
```

Then define a hostname for the Pi in your SSH config. To do this, add this entry to your `~/.ssh/config` file, with <USERNAME> being the username you set during the imager setup:
```
Host microban
    HostName 192.168.XXX.XXX
    User <USERNAME>
```

Finally, you can connect to the Pi with
```
ssh microban
```

In order not to have to enter the password everytime you connect to the Pi, you can copy your SSH key to the Pi. If you don't have an SSH key, you can generate one by running:
```
ssh-keygen -t ed25519
```

Then, copy your SSH key to the Pi with:
```
ssh-copy-id microban
```

Now you can connect to the Pi without entering a password!

## Raspberry Pi configuration

Copy the configuration file to the Pi. From your computer, run:
```
scp docs/dev/config.txt microban:config.txt
```

Then, on the Pi, move the configuration file to the correct location:
```
sudo mv config.txt /boot/firmware/config.txt
```

Reboot the Pi with `sudo reboot` for the changes to take effect.

After rebooting, connect to the Pi with `ssh microban` and setup the raspi-config:
- run `sudo raspi-config`
    - go to Interface Options
        - go to I2C
            - enable I2C    
        - go to Serial Port
            - disable Serial Console
            - enable Serial Port

Then, to prevent ssh hangs when the Pi is idle, run:
```
sudo nmcli con mod <tab_to_find_your_wifi_connection> wifi.powersave disable
```

Finally desactivate automatic updates by running 
```
sudo touch /etc/apt/apt.conf.d/99disable-auto-upgrades
cat << 'EOF' | sudo tee /etc/apt/apt.conf.d/99disable-auto-upgrades > /dev/null
APT::Periodic::Update-Package-Lists "0";
APT::Periodic::Download-Upgradeable-Packages "0";
APT::Periodic::AutocleanInterval "0";
APT::Periodic::Unattended-Upgrade "0";
EOF
```

Reboot the Pi with `sudo reboot`.

Install uv, the Python package manager, on the Pi. First, set the date:
```
sudo date -s "2026-06-27 12:21:00"
```

Then, run:
```
curl -LsSf https://astral.sh/uv/install.sh | sh
```

## SSH host-key regeneration

A distributed image must not ship with fixed SSH host keys — otherwise every robot
flashed from it shares the same keys (a security risk, and SSH host-key conflicts when
two robots run on the same network). We remove the keys before imaging (see below) and
let each robot regenerate its own on first boot.

Raspberry Pi OS already ships `sshd-keygen.service`, but it only runs when
`ConditionFirstBoot=yes` (i.e. `/etc/machine-id` is empty). Add a more robust service,
triggered by the **absence of host keys**, so they always regenerate when missing.

On the Pi (`ssh microban`):
```bash
sudo tee /etc/systemd/system/regen-ssh-host-keys.service >/dev/null <<'EOF'
[Unit]
Description=Regenerate SSH host keys if missing
Before=ssh.service ssh.socket sshd.service
ConditionPathExists=!/etc/ssh/ssh_host_ed25519_key

[Service]
Type=oneshot
RemainAfterExit=yes
ExecStart=/usr/bin/ssh-keygen -A

[Install]
WantedBy=multi-user.target
EOF

sudo systemctl enable regen-ssh-host-keys.service
```

## Wi-Fi: use NetworkManager `.nmconnection` files, not `network-config`

`network-config` (cloud-init's netplan-based Wi-Fi config) does not work on this image:
cloud-init depends on a module, `cc_netplan_nm_patch`, to translate a netplan Wi-Fi entry
into an actual NetworkManager connection, and that module is missing. The config
validates with no error and `netplan generate` reports success, but no
`/etc/NetworkManager/system-connections/*.nmconnection` file — and therefore no real
connection — ever gets written, on first boot or after a cloud-init reset (the
service below).

The confirmed-working method is to write the `.nmconnection` file directly, offline, with
the SD card mounted on your PC (`$R` = `/media/$USER/rootfs`):
```bash
UUID=$(uuidgen)
sudo tee "$R/etc/NetworkManager/system-connections/home.nmconnection" >/dev/null <<EOF
[connection]
id=<SSID>
uuid=$UUID
type=wifi
autoconnect=true

[wifi]
mode=infrastructure
ssid=<SSID>

[wifi-security]
key-mgmt=wpa-psk
psk=<PASSWORD>

[ipv4]
method=auto

[ipv6]
method=auto
addr-gen-mode=default

[proxy]
EOF
sudo chown root:root "$R/etc/NetworkManager/system-connections/home.nmconnection"
sudo chmod 600 "$R/etc/NetworkManager/system-connections/home.nmconnection"
```
The file must be `root:root` / `600`, or NetworkManager silently ignores it. See
[deployment.md](../deployment.md#step-2-headless-wi-fi-configuration) for the full
walkthrough (multiple networks, changing Wi-Fi later, country code).

### `network-config` re-application service

`network-config` is read by cloud-init only on the first boot. This service detects a
changed `network-config` at boot and resets cloud-init so that it is read again. As
explained above, this does not create a Wi-Fi connection on this image.

On the Pi (`ssh microban`):
```bash
sudo tee /usr/local/bin/microban-netcfg-reapply >/dev/null <<'EOF'
#!/bin/bash
# Re-apply /boot/firmware/network-config when it changes, by resetting cloud-init.
set -u

CFG=/boot/firmware/network-config
STAMP=/var/lib/microban/netcfg.sha256

[ -f "$CFG" ] || exit 0
mkdir -p "$(dirname "$STAMP")"

new=$(sha256sum "$CFG" | awk '{print $1}')
old=$(cat "$STAMP" 2>/dev/null || true)

if [ -z "$old" ]; then
    # First run: cloud-init already applied this config this boot. Just record it.
    echo "$new" > "$STAMP"
    exit 0
fi

if [ "$new" != "$old" ]; then
    # Config changed: record it, reset cloud-init, and reboot so cloud-init
    # re-applies the new network-config on the next boot.
    echo "$new" > "$STAMP"
    /usr/bin/cloud-init clean --logs
    /usr/sbin/reboot
fi
EOF
sudo chmod 755 /usr/local/bin/microban-netcfg-reapply

sudo tee /etc/systemd/system/microban-netcfg-reapply.service >/dev/null <<'EOF'
[Unit]
Description=Re-apply network-config (reset cloud-init) when it changes
After=cloud-final.service
ConditionPathExists=/boot/firmware/network-config

[Service]
Type=oneshot
ExecStart=/usr/local/bin/microban-netcfg-reapply

[Install]
WantedBy=multi-user.target
EOF

sudo systemctl enable microban-netcfg-reapply.service
```

## Serial console off, motor UART on fix

The Dynamixel motors are driven over the UART (`/dev/ttyAMA0`, 1 Mbps). The serial
**login console** must be **disabled** on that UART, otherwise the kernel and a getty
spew bytes onto the bus and the motors return checksum errors / stop responding. The
UART **hardware** must stay **enabled**.

⚠️ Setting this with `raspi-config` is **not enough on its own**: this image is driven
by cloud-init, whose `user-data` contains `rpi.interfaces.serial`. If it is set to
`true`, cloud-init **re-enables the serial console** every time it runs as a new
instance — which happens on every `cloud-init clean`, including the one the
`microban-netcfg-reapply` service triggers on a Wi-Fi change. So a raspi-config tweak
gets silently reverted and the motors break again.

Fix it at the source. Edit `/boot/firmware/user-data` and set the granular form
(console off, hardware on):
```yaml
rpi:
  interfaces:
    serial:
      console: false
      hardware: true
```
Validate the file, then apply it cleanly:
```bash
sudo cloud-init schema -c /boot/firmware/user-data   # must report "Valid schema"
sudo cloud-init clean && sudo reboot
```
After reboot, confirm `/proc/cmdline` no longer contains `console=ttyAMA0` and that the
motors answer (`rustypot_wizard` at 1 Mbps sees all 19 IDs). This config survives every
cloud-init re-run, so the motors stay reachable.

> If cloud-init rejects the granular form on your version, the fallback is to remove the
> `rpi.interfaces.serial` line entirely (cloud-init then leaves the serial alone) — the
> UART stays on via `enable_uart=1` in `config.txt`, and you disable the console once
> with `raspi-config` (Interface Options → Serial Port → login shell: No, hardware: Yes).

### Device permissions

Reading `/dev/input/js*` requires membership in the `input` group (otherwise you'd
need root):

```
sudo usermod -aG input $USER
```

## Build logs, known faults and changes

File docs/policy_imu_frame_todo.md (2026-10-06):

# TODO: align IMU observations across policies

The immediate PICO v12 frame mismatch has been corrected in the robot runtime:
the v12 actor receives raw BMI088 gyro values in the IMU site's local axes,
matching Mjlab's `robot/imu_ang_vel` observation and the v12 ONNX metadata
`base_ang_vel_frame=imu_sensor_xyz`. This correction does not change the v12
checkpoint or ONNX action weights. Broader frame unification remains follow-up
work after the get-up retraining milestone.

The TWIST2 tracking actor, velocity walking actor, get-up actor, and PICO v12
training actor read `robot/imu_ang_vel` in the IMU site's local axes. The robot
feeds raw BMI088 gyro values to walking, get-up and PICO, and contract
microban-policy-1 requires `base_ang_vel_frame=imu_sensor_xyz` of all three
(docs/policies.md). A separate train/export/runtime audit should verify the
physical axis signs.

For broader unification:

1. Check the physical BMI088 axis signs against the MJCF IMU site and the
   recorded actor observation for TWIST2, walking, and each teleop recipe.
2. Pick one explicit observation frame per model. Update its training config,
   checkpoint provenance, ONNX metadata, and robot observation builder together.
3. Export a newly authenticated ONNX, evaluate it in simulation, and verify the
   actual robot behavior before replacing the working artifact.

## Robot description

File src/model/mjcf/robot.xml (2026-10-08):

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
<mujoco model="microban">
  <compiler angle="radian" meshdir="assets" autolimits="true"/>
  <default>
    <default class="microban">
      <joint frictionloss="0.1" armature="0.005"/>
      <position kp="50" dampratio="1"/>
      <default class="visual">
        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
      </default>
      <default class="collision">
        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
      </default>
    </default>
    <default class="xl330">
      <joint damping="0.041" frictionloss="0.013" armature="0.0018"/>
      <motor gear="1"/>
    </default>
  </default>
  <sensor>
    <framequat name="orientation" objtype="site" noise="0.001" objname="imu"/>
    <gyro name="angular-velocity" site="imu" noise="0.005"/>
    <gyro name="imu_ang_vel" site="imu"/>
    <velocimeter name="imu_lin_vel" site="imu"/>
    <accelerometer name="imu_accel" site="imu"/>
    <subtreeangmom name="root_angmom" body="trunk"/>
  </sensor>
  <worldbody>
    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
    <body name="trunk" pos="0 0 0" quat="1 0 0 0" childclass="microban">
      <freejoint name="trunk_freejoint"/>
      <inertial pos="-0.00632399 -0.000119739 0.0527636" mass="0.435626" fullinertia="0.000795351 0.000594437 0.000457518 1.28286e-06 -8.71511e-06 1.35427e-07"/>
      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
      <body name="head" pos="0.01295835 0 0.126" quat="0.707107 0 0 0.707107">
        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
        <joint axis="0 0 1" name="head" type="hinge" range="-1.5707963267949783 1.5707963267948148" class="xl330"/>
        <inertial pos="2.7845e-06 0.0365054 0.0116475" mass="0.0318353" fullinertia="1.04883e-05 4.65868e-06 8.45675e-06 -2.52545e-10 2.90295e-10 -1.82954e-06"/>
        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
        <body name="roll_pitch_link" pos="0 0.0574 0.0225" quat="0.707107 0 0 -0.707107">
          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
          <joint axis="1 0 0" name="neck_roll" type="hinge" range="-0.436332 0.436332" class="xl330"/>
          <inertial pos="0.0388655 0.000480036 0.000773406" mass="0.036182" fullinertia="3.91484e-06 1.46342e-05 1.5668e-05 -2.70928e-07 8.1584e-07 1.28618e-08"/>
          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
          <body name="camera_cover" pos="0.0574 0.0125 0" quat="1 0 0 0">
            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
            <joint axis="0 1 0" name="neck_pitch" type="hinge" range="-1.570796 0.436332" class="xl330"/>
            <inertial pos="0.0228923 -0.0124774 -9.01111e-06" mass="0.0360838" fullinertia="2.43676e-05 6.25347e-06 2.78637e-05 3.98036e-09 -9.31931e-10 -3.83045e-10"/>
            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
          </body>
        </body>
      </body>
      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
      <body name="shoulder" pos="0 -0.0505 0.081" quat="0.707107 -0.707107 -0 0">
        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
        <joint axis="0 0 1" name="right_shoulder_pitch" type="hinge" range="-3.141592653589793 3.141592653589793" class="xl330"/>
        <inertial pos="0 2e-08 -0.00706356" mass="0.0109724" fullinertia="1.24848e-06 1.88675e-06 2.30754e-06 9.3949e-13 8.75796e-13 -5.10696e-12"/>
        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
        <body name="humerus__configuration_right" pos="0.0145 0 -0.0195" quat="0 0.707107 0 0.707107">
          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
          <joint axis="0 0 1" name="right_shoulder_roll" type="hinge" range="-3.1415926535897922 8.881784197001252e-16" class="xl330"/>
          <inertial pos="-0.000336107 -0.0256295 -0.014388" mass="0.0514058" fullinertia="2.27714e-05 4.54224e-06 2.26534e-05 -3.99353e-07 -3.07588e-09 -1.01984e-07"/>
          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
          <body name="radius" pos="-0.0145 -0.0515 -0.0145" quat="0.707107 0 0.707107 -0">
            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
            <joint axis="0 0 1" name="right_elbow" type="hinge" range="-2.181661564992912 2.181661564992912" class="xl330"/>
            <inertial pos="-1.47596e-49 -0.0340122 0.013482" mass="0.0274072" fullinertia="1.04007e-05 2.61603e-06 8.7794e-06 -1.35741e-55 -4.61882e-21 1.23991e-08"/>
            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
          </body>
        </body>
      </body>
      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
      <body name="hip" pos="0 -0.036 0" quat="1 -0 -0 0">
        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
        <joint axis="0 0 1" name="right_hip_yaw" type="hinge" range="-4.188790204786353 1.047197551196635" class="xl330"/>
        <inertial pos="-0.00961017 -1e-08 -0.00765825" mass="0.00975549" fullinertia="8.75612e-07 4.32851e-06 4.26238e-06 3.1365e-12 -5.43397e-08 5.66659e-14"/>
        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
        <body name="hip_block__configuration_right" pos="-0.0375 0 -0.0214" quat="0.5 -0.5 0.5 -0.5">
          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
          <joint axis="0 0 1" name="right_hip_roll" type="hinge" range="-0.436332 0.436332" class="xl330"/>
          <inertial pos="-6.14702e-05 0.00950161 0.0264325" mass="0.0583697" fullinertia="1.9229e-05 1.54487e-05 9.4077e-06 -1.04246e-08 1.01993e-07 4.97642e-07"/>
          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
          <body name="femur__configuration_right" pos="-0.0145 -0 0.0385" quat="0 0.707107 0 -0.707107">
            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
            <joint axis="0 0 1" name="right_hip_pitch" type="hinge" range="-1.5707963267948974 1.5707963267948957" class="xl330"/>
            <inertial pos="-0.0108175 -0.0387251 -0.0147455" mass="0.017273" fullinertia="1.07363e-05 5.15428e-06 8.2932e-06 -1.74349e-06 1.34774e-09 2.21702e-09"/>
            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
            <body name="tibia__configuration_right" pos="-0.005 -0.062 -0" quat="1 -0 0 -0">
              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
              <joint axis="0 0 1" name="right_knee" type="hinge" range="-0.7853981633977201 2.356194490192073" class="xl330"/>
              <inertial pos="0.00255695 -0.017402 -0.014454" mass="0.0350657" fullinertia="1.56776e-05 5.89266e-06 1.42103e-05 2.45892e-06 9.47282e-08 -1.67523e-07"/>
              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
              <body name="ankle_block__configuration_left" pos="0.008 -0.0612131 -0" quat="0 -0 -0 1">
                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
                <joint axis="0 0 1" name="right_ankle_pitch" type="hinge" range="-1.5707963267948077 0.6108652381981041" class="xl330"/>
                <inertial pos="-0.0117978 -0.00944623 -0.014397" mass="0.0577288" fullinertia="9.35052e-06 1.50215e-05 1.88085e-05 -4.11424e-07 -6.78719e-08 -5.72456e-09"/>
                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
                <body name="foot" pos="-0.0385 0 -0.0145" quat="0 -0.707107 0 -0.707107">
                  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
                  <joint axis="0 0 1" name="right_ankle_roll" type="hinge" range="-0.610865238197748 0.6108652381982826" class="xl330"/>
                  <inertial pos="4e-08 -0.0200677 0.033616" mass="0.0301613" fullinertia="1.301e-05 1.45047e-05 3.78583e-06 2.39016e-11 4.01609e-11 6.0526e-07"/>
                  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
                </body>
              </body>
            </body>
          </body>
        </body>
      </body>
      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
      <body name="shoulder_2" pos="-0 0.0505 0.081" quat="0 0 -0.707107 -0.707107">
        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
        <joint axis="0 0 1" name="left_shoulder_pitch" type="hinge" range="-3.141592653589793 3.141592653589793" class="xl330"/>
        <inertial pos="0 2e-08 0.00706356" mass="0.0109724" fullinertia="1.24846e-06 1.88675e-06 2.30752e-06 1.13057e-12 8.75796e-13 -2.69282e-12"/>
        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
        <body name="humerus__configuration_left" pos="-0.0145 0 0.0195" quat="0 -0.707107 -0 0.707107">
          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
          <joint axis="0 0 1" name="left_shoulder_roll" type="hinge" range="0.0 3.141592653589793" class="xl330"/>
          <inertial pos="-0.000339641 0.0256295 -0.0143843" mass="0.0514058" fullinertia="2.27714e-05 4.54204e-06 2.26533e-05 3.97343e-07 -8.65028e-10 9.9835e-08"/>
          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
          <body name="radius_2" pos="-0.0145 0.0515 -0.0145" quat="0.707107 0 -0.707107 0">
            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
            <joint axis="0 0 1" name="left_elbow" type="hinge" range="-2.1816615649929156 2.1816615649929085" class="xl330"/>
            <inertial pos="-5.20417e-18 0.0340122 -0.013482" mass="0.0274072" fullinertia="1.04007e-05 2.61603e-06 8.7794e-06 1.35741e-55 4.61882e-21 1.23991e-08"/>
            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
          </body>
        </body>
      </body>
      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
      <body name="hip_2" pos="-0 0.036 0" quat="0 -0 0 -1">
        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
        <joint axis="0 0 1" name="left_hip_yaw" type="hinge" range="-1.0471975511965976 4.1887902047863905" class="xl330"/>
        <inertial pos="0.00961017 1e-08 -0.00765825" mass="0.00975549" fullinertia="8.75616e-07 4.32851e-06 4.26238e-06 8.24528e-13 5.43397e-08 -3.62598e-14"/>
        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
        <body name="hip_block__configuration_left" pos="0.0375 0 -0.0214" quat="0.5 -0.5 -0.5 0.5">
          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

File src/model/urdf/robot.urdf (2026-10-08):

<?xml version="1.0" ?>
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
<robot name="urdf">
  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
  <link name="trunk">
    <inertial>
      <origin xyz="-0.00632399 -0.000119739 0.0527636" rpy="0 0 0"/>
      <mass value="0.435626"/>
      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
    </inertial>
    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
  </link>
  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
  <link name="body">
    <origin xyz="0 0 0" rpy="0 -0 0"/>
    <inertial>
      <origin xyz="0 0 0" rpy="0 0 0"/>
      <mass value="1e-9"/>
      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
    </inertial>
  </link>
  <joint name="body_frame" type="fixed">
    <origin xyz="0 0 0" rpy="0 0 0"/>
    <parent link="trunk"/>
    <child link="body"/>
    <axis xyz="0 0 0"/>
  </joint>
  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
  <link name="imu">
    <origin xyz="0 0 0" rpy="0 -0 0"/>
    <inertial>
      <origin xyz="0 0 0" rpy="0 0 0"/>
      <mass value="1e-9"/>
      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
    </inertial>
  </link>
  <joint name="imu_frame" type="fixed">
    <origin xyz="0.01483 -0.002 0.0675" rpy="1.5708 -0 -1.5708"/>
    <parent link="trunk"/>
    <child link="imu"/>
    <axis xyz="0 0 0"/>
  </joint>
  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
  <link name="head">
    <inertial>
      <origin xyz="2.7845e-06 0.0365054 0.0116475" rpy="0 0 0"/>
      <mass value="0.0318353"/>
      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
    </inertial>
    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
  </link>
  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
  <joint name="head" type="revolute">
    <origin xyz="0.01295835 0 0.126" rpy="0 0 1.5708"/>
    <parent link="trunk"/>
    <child link="head"/>
    <axis xyz="0 0 1"/>
    <limit effort="10" velocity="10" lower="-1.5708" upper="1.5708"/>
  </joint>
  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
  <link name="roll_pitch_link">
    <inertial>
      <origin xyz="0.0388655 0.000480036 0.000773406" rpy="0 0 0"/>
      <mass value="0.036182"/>
      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
    </inertial>
    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
  </link>
  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
  <joint name="neck_roll" type="revolute">
    <origin xyz="0 0.0574 0.0225" rpy="0 0 -1.5708"/>
    <parent link="head"/>
    <child link="roll_pitch_link"/>
    <axis xyz="1 0 0"/>
    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
    <limit effort="10" velocity="10" lower="-0.436332" upper="0.436332"/>
  </joint>
  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
  <link name="camera_cover">
    <inertial>
      <origin xyz="0.0228923 -0.0124774 -9.01111e-06" rpy="0 0 0"/>
      <mass value="0.0360838"/>
      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
    </inertial>
    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
  </link>
  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
  <joint name="neck_pitch" type="revolute">
    <origin xyz="0.0574 0.0125 0" rpy="0 0 0"/>
    <parent link="roll_pitch_link"/>
    <child link="camera_cover"/>
    <axis xyz="0 1 0"/>
    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
    <limit effort="10" velocity="10" lower="-1.570796" upper="0.436332"/>
  </joint>
  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
  <link name="camera_left">
    <origin xyz="0 0 0" rpy="0 0 0"/>
    <inertial>
      <origin xyz="0 0 0" rpy="0 0 0"/>
      <mass value="1e-9"/>
      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
    </inertial>
  </link>
  <joint name="camera_left_frame" type="fixed">
    <origin xyz="0.040002 0.017008 0.00003" rpy="0 0 0"/>
    <parent link="camera_cover"/>
    <child link="camera_left"/>
    <axis xyz="0 0 0"/>
  </joint>
  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
  <link name="camera_right">
    <origin xyz="0 0 0" rpy="0 0 0"/>
    <inertial>
      <origin xyz="0 0 0" rpy="0 0 0"/>
      <mass value="1e-9"/>
      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
    </inertial>
  </link>
  <joint name="camera_right_frame" type="fixed">
    <origin xyz="0.040002 -0.042008 -2.1e-05" rpy="0 0 0"/>
    <parent link="camera_cover"/>
    <child link="camera_right"/>
    <axis xyz="0 0 0"/>
  </joint>
  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
  <link name="shoulder">
    <inertial>
      <origin xyz="0 2e-08 -0.00706356" rpy="0 0 0"/>
      <mass value="0.0109724"/>
      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
    </inertial>
    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
  </link>
  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
  <link name="humerus__configuration_right">
    <inertial>
      <origin xyz="-0.000336107 -0.0256295 -0.014388" rpy="0 0 0"/>
      <mass value="0.0514058"/>
      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
    </inertial>
    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
  </link>
  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
  <link name="radius">
    <inertial>
      <origin xyz="-1.47596e-49 -0.0340122 0.013482" rpy="0 0 0"/>
      <mass value="0.0274072"/>
      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
    </inertial>
    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
  </link>
  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
  <joint name="right_elbow" type="revolute">
    <origin xyz="-0.0145 -0.0515 -0.0145" rpy="-0 1.5708 0"/>
    <parent link="humerus__configuration_right"/>
    <child link="radius"/>
    <axis xyz="0 0 1"/>
    <limit effort="10" velocity="10" lower="-2.18166" upper="2.18166"/>
  </joint>
  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
  <joint name="right_shoulder_roll" type="revolute">
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

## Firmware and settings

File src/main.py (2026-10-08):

# SPDX-License-Identifier: GPL-3.0-or-later
# Copyright 2026 Marc Duclusaud

import time
import numpy as np
import os
from pathlib import Path

from constants import MOTOR_TO_ID, NEUTRAL_POSE, KP_HARDWARE_NEUTRAL
from robot_controller import RobotController
from scheduler import Scheduler
from input.input_source import InputSource
from input.keyboard_input import KeyboardInputSource
from moves.hmd_head import HmdHeadTrackingMove
from moves.getup import GetupMove
from moves.pico_arms import PicoArmTargetHold, PicoArmTrackingMove
from moves.policy_selector import PolicySelectableWalkMove
from moves.rotate_head import RotateHeadMove
from moves.squat import SquatMove

PID_FILE = Path("/tmp/microban_scheduler.pid")


def _another_session_running() -> bool:
    """True if a live control loop already owns the PID file (e.g. launched by the
    gamepad daemon). Avoids two instances fighting over the motor bus."""
    if not PID_FILE.exists():
        return False
    try:
        pid = int(PID_FILE.read_text(encoding="ascii").strip())
        os.kill(pid, 0)
    except (ValueError, OSError):
        return False
    return True

# Which moves can be toggled from the gamepad / keyboard. "getup" is also switched
# automatically by the scheduler on a sustained fall (see Scheduler._update_getup_override);
# the key/button here is a manual override for testing. A/B/R3 are reserved for get-up policy testing
# (see GamepadInputSource) and cannot be reassigned here.
MOVE_KEYS = {"h": "head", "s": "squat", "v": "walk", "g": "getup"}
GAMEPAD_BUTTON_MOVES = {"X": "walk"}


def build_input_source() -> InputSource:
    """Use the gamepad when one is connected, otherwise fall back to the keyboard.

    Override with MICROBAN_INPUT=keyboard|gamepad|network. Network mode listens for
    the external VR bridge on MICROBAN_NETWORK_PORT (default 5555).
    """
    requested = os.environ.get("MICROBAN_INPUT", "auto").lower()

    if requested == "network":
        from input.network_input import NetworkInputSource

        port = int(os.environ.get("MICROBAN_NETWORK_PORT", "5555"))
        allowed_remote = os.environ.get("MICROBAN_NETWORK_ALLOWED_IP") or None
        allowed_remote_file = os.environ.get("MICROBAN_NETWORK_ALLOWED_IP_FILE") or None
        return NetworkInputSource(
            port=port,
            allowed_remote=allowed_remote,
            allowed_remote_file=allowed_remote_file,
        )

    if requested not in ("auto", "keyboard", "gamepad"):
        raise ValueError(
            f"Unknown MICROBAN_INPUT={requested!r}; use auto, keyboard, gamepad, or network."
        )

    if requested in ("auto", "gamepad"):
        from input.gamepad_input import GamepadInputSource, find_gamepad_path

        if find_gamepad_path() is not None:
            return GamepadInputSource(button_moves=GAMEPAD_BUTTON_MOVES)
        if requested == "gamepad":
            raise RuntimeError("MICROBAN_INPUT=gamepad but no gamepad was found.")
        print("No gamepad detected; using keyboard input.")

    return KeyboardInputSource(move_keys=MOVE_KEYS)


def ramp_to_neutral(controller: RobotController, duration_s: float = 2.0) -> None:
    """Ramp all motors smoothly to neutral position before starting the control loop."""
    motor_ids = list(MOTOR_TO_ID.values())
    initial_positions = np.array(controller.sync_read_present_position(motor_ids))
    target_neutral = np.array([NEUTRAL_POSE[name] for name in MOTOR_TO_ID])

    print("Ramping all motors to neutral position...")
    start_time = time.perf_counter()
    elapsed_time = 0.0

    while elapsed_time < duration_s:
        elapsed_time = time.perf_counter() - start_time
        progress = min(elapsed_time / duration_s, 1.0)
        target_positions = initial_positions + progress * (target_neutral - initial_positions)
        controller.sync_write_goal_position(motor_ids, target_positions.flatten().tolist())

    controller.sync_write_goal_position(motor_ids, target_neutral.tolist())
    print("All motors reached neutral position.")


def main() -> None:
    if _another_session_running():
        print("A control loop is already running (see the PID file); aborting.")
        return

    PID_FILE.write_text(f"{os.getpid()}\n", encoding="ascii")

    controller: RobotController | None = None
    scheduler: Scheduler | None = None
    try:
        input_source = build_input_source()
        controls_motor_power = bool(
            getattr(input_source, "controls_motor_power", False)
        )
        force_start_off_value = os.environ.get(
            "MICROBAN_START_TORQUE_OFF", "0"
        ).strip().lower()
        if force_start_off_value not in {"0", "1", "false", "true", "no", "yes"}:
            raise ValueError(
                "MICROBAN_START_TORQUE_OFF must be 0/1, false/true, or no/yes"
            )
        force_start_off = force_start_off_value in {"1", "true", "yes"}
        if force_start_off and not controls_motor_power:
            raise ValueError(
                "MICROBAN_START_TORQUE_OFF requires an input source with the "
                "B/A/R3 hardware-power gate (use MICROBAN_INPUT=network or gamepad)"
            )
        serial_hold_value = os.environ.get(
            "MICROBAN_SERIAL_HOLD_LAST_ON_ERROR", "0"
        ).strip().lower()
        if serial_hold_value not in {"0", "1", "false", "true", "no", "yes"}:
            raise ValueError(
                "MICROBAN_SERIAL_HOLD_LAST_ON_ERROR must be 0/1, "
                "false/true, or no/yes"
            )
        serial_hold_on_error = serial_hold_value in {"1", "true", "yes"}

        controller = RobotController()
        motor_ids = list(MOTOR_TO_ID.values())
        start_limp = controls_motor_power or force_start_off
        if start_limp:
            # This is deliberately the first motor-bus write after opening the
            # controller; a prior process may have exited without clearing the
            # servos' persistent torque-enable registers.
            controller.sync_write_torque_enable(
                motor_ids, [False] * len(motor_ids)
            )
        controller.sync_write_status_return_level(motor_ids, [1] * len(motor_ids))
        # The one startup gain write: every servo is told the static holding
        # gain, so RobotController knows each servo's gain from here on.
        controller.sync_write_kp(motor_ids, [KP_HARDWARE_NEUTRAL] * len(motor_ids))

        if start_limp:
            print(
                "Hardware-gated startup: all-joint torque OFF; press A to enable "
                "torque and return slowly to neutral."
            )
        else:
            controller.sync_write_torque_enable(
                motor_ids, [True] * len(motor_ids)
            )
            ramp_to_neutral(controller)

        arm_target_hold = PicoArmTargetHold()
        scheduler = Scheduler(
            frequency_hz=50.0,
            controller=controller,
            input_source=input_source,
            hardware_power_control=controls_motor_power,
            serial_hold_on_error=serial_hold_on_error,
            moves={
                "head": RotateHeadMove(),
                "squat": SquatMove(),
                "walk": PolicySelectableWalkMove(
                    controller=controller, arm_target_hold=arm_target_hold
                ),
                # Ordered after walk so the right-trigger direct IK path owns
                # only the six arm joints in both standing and walking modes.
                # The PICO policy observes the targets it writes, one cycle late.
                "pico_arms": PicoArmTrackingMove(
                    controller=controller, arm_target_hold=arm_target_hold
                ),
                "hmd_head": HmdHeadTrackingMove(),
                "getup": GetupMove(controller=controller),
            },
        )

        for move in scheduler.registered_moves.values():
            move.preload()

        # Flush stale UART bytes accumulated during preload
        for _ in range(10):
            try:
                controller.sync_read_present_position(motor_ids)
            except RuntimeError:
                pass

        scheduler.run()

    finally:
        # Scheduler.run() owns normal cleanup. Cover initialization/preload failures
        # that happen after torque was enabled but before its finally block begins.
        if controller is not None and (scheduler is None or not scheduler._cleanup_done):
            try:
                motor_ids = list(MOTOR_TO_ID.values())
                controller.sync_write_torque_enable(motor_ids, [False] * len(motor_ids))
            finally:
                shutdown = getattr(controller, "shutdown", None)
                if callable(shutdown):
                    shutdown()
        if PID_FILE.exists():
            PID_FILE.unlink()


if __name__ == "__main__":
    main()

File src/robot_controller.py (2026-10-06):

# SPDX-License-Identifier: GPL-3.0-or-later
# Copyright 2026 Marc Duclusaud

from rustypot import Xl330PyController
import numpy as np
import math
import time

from constants import (
    HARDWARE_JOINT_OFFSET_MAX_RAD,
    HARDWARE_JOINT_OFFSET_RAD,
    IMU_I2C_BUS,
    MOTOR_SIGN,
    MOTOR_TO_ID,
    NEUTRAL_POSE,
    PRESENT_CURRENT_UNIT_A,
    SERVO_GOAL_MAX_RAD,
    SERVO_GOAL_MIN_RAD,
)
from imu_reader import ThreadedIMUReader


TORQUE_VERIFY_TIMEOUT_S = 1.0
# XC330 raw goal range in Position Control mode and the factory Min/Max
# Position Limit register values.
SERVO_GOAL_RAW_MIN = 0
SERVO_GOAL_RAW_MAX = 4095
POSITION_CONTROL_MODE = 3
SERVO_CONFIG_READ_ATTEMPTS = 3


def validated_hardware_offsets(offsets: dict[str, float]) -> dict[str, float]:
    """Check a per-joint real-robot offset table (logical radians)."""
    missing = sorted(set(MOTOR_TO_ID) - set(offsets))
    unknown = sorted(set(offsets) - set(MOTOR_TO_ID))
    if missing or unknown:
        raise ValueError(
            f"hardware joint offsets must list every joint: missing={missing}, unknown={unknown}"
        )
    checked = {}
    for name in MOTOR_TO_ID:
        value = float(offsets[name])
        if not math.isfinite(value) or abs(value) > HARDWARE_JOINT_OFFSET_MAX_RAD:
            raise ValueError(
                f"hardware joint offset {name}={offsets[name]!r} rad must be finite "
                f"and within +-{HARDWARE_JOINT_OFFSET_MAX_RAD} rad"
            )
        # "+ 0.0" turns a typed -0.0 into +0.0 so a zero entry never changes
        # the sign of a zero reading (bit-for-bit identity with no offset).
        checked[name] = value + 0.0
    return checked


def saturate_servo_goal(
    servo: float,
    lower: float = SERVO_GOAL_MIN_RAD,
    upper: float = SERVO_GOAL_MAX_RAD,
) -> float:
    """Clamp a servo-coordinate goal (rad) into a servo's goal range.

    XC330 in Position Control mode takes raw goals 0..4095 (one turn), which
    rustypot maps to [SERVO_GOAL_MIN_RAD, SERVO_GOAL_MAX_RAD] = [-pi, pi -
    2*pi/4096], the default bounds. A servo whose Min/Max Position Limit
    registers are narrower gets its own bounds (``servo_goal_bounds``), since
    it rejects a goal outside them and keeps its previous one. Policies have
    no software clip (their targets reach +-pi) and the sign/offset mapping can
    push a goal past either edge, so every goal write saturates here. An
    in-range value is returned unchanged (the same float, bit for bit). A
    non-finite goal raises; the write path never passes one (it holds that
    joint's last goal instead).
    """
    if not math.isfinite(servo):
        raise ValueError(f"non-finite servo goal {servo!r}")
    if servo < lower:
        return lower
    if servo > upper:
        return upper
    return servo


def servo_raw_to_rad(raw: int) -> float:
    """rustypot's position mapping, raw = (rad + pi) * 4096 / (2*pi), inverted."""
    return 2.0 * math.pi * raw / 4096.0 - math.pi


def _rad_to_raw_exact(rad: float) -> float:
    return (rad + math.pi) * 4096.0 / (2.0 * math.pi)


def servo_goal_bounds(raw_min: int, raw_max: int) -> tuple[float, float]:
    """Goal bounds (servo rad) for Min/Max Position Limit registers.

    The limits are intersected with the raw goal range 0..4095; the full range
    returns exactly (SERVO_GOAL_MIN_RAD, SERVO_GOAL_MAX_RAD). A narrowed edge
    is nudged up by at most a few ulps so rustypot's raw conversion (it
    truncates; verified on its sync-write bytes) lands exactly on the limit
    (rounding would too). Raises ValueError when the intersection holds fewer
    than two raw values (Min Position Limit at or above Max Position Limit):
    such a servo cannot move, and a zero-width range is more likely a corrupt
    read than a real setting.
    """
    low = max(SERVO_GOAL_RAW_MIN, int(raw_min))
    high = min(SERVO_GOAL_RAW_MAX, int(raw_max))
    if low >= high:
        raise ValueError(f"no usable position limit range raw [{raw_min}, {raw_max}]")
    lower = SERVO_GOAL_MIN_RAD if low == SERVO_GOAL_RAW_MIN else servo_raw_to_rad(low)
    upper = SERVO_GOAL_MAX_RAD if high == SERVO_GOAL_RAW_MAX else servo_raw_to_rad(high)
    while _rad_to_raw_exact(lower) < low:
        lower = math.nextafter(lower, math.inf)
    while _rad_to_raw_exact(upper) < high:
        upper = math.nextafter(upper, math.inf)
    return lower, upper


class ServoConfigurationError(Exception):
    """A servo's EEPROM configuration the runtime cannot drive.

    Deliberately not a RuntimeError: the scheduler treats RuntimeError as a
    transient serial fault and may hold through it.
    """


class RobotController:
    """Wraps Xl330PyController.

    Every value above this class (goals, measurements, caches, last goal
    targets) is in the logical joint coordinate used by the policies and
    training. ``_to_servo``/``_from_servo`` are the only conversions to and from
    the servo coordinate: MOTOR_SIGN plus the real-robot calibration offset
    (constants.HARDWARE_JOINT_OFFSET_RAD). Every servo goal written to the bus
    is saturated into that servo's goal range (``saturate_servo_goal``): raw
    0..4095 intersected with its Min/Max Position Limit, read at startup.
    """
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

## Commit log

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2026-09-21 Fix invalid XML: remove double-hyphen sequences from URDF comments
    XML comments cannot contain "--" in their body. Two comments added in the
    previous commit used " -- " as a dash separator, which made the URDF
    not well-formed. Replaced with a single hyphen.
    Claude-Session: https://claude.ai/code/session_0122vqQiRGmFNNwgYCePnSBu
    [robot.urdf]
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2026-09-21 Close 17.5mm gap between hip roll-mount flange and hip_block free horn
    The hip bracket's roll-mount flange (the boss that meets the hip_roll
    servo's free/idle horn, DC15_A01_HORN_IDLE2_DUMMY, on the opposite side
    of hip_block from the driven XL330 horn) was sitting 17.5mm short of
    the horn, leaving the connecting arm floating with a visible gap. This
    was independent of the earlier yaw/pitch axis fix and the hip_block
    chain repositioning; measured directly via Fusion's measureMinimumDistance
    between the flange's bore face and the free horn body.
    Split the arm just inside the fillet that blends the round neck into
    the flange boss, translated the boss (with its bore and 4 bolt holes
    intact) 17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
    [hip.step, hip.stl]
2026-09-21 Re-apply hip/leg yaw alignment fix after accidental undo
    An in-progress part edit's Undo had reverted the hip yaw-axis alignment
    (hip:1/hip:2 occurrence positions, leg-chain wrappers, and their mounting
    screws). Redid the same 17.5mm front-back correction so the hip ->
    hip_block -> femur -> tibia -> ankle_block -> foot chain is fully
    connected again (0.000000cm gaps end-to-end) for both legs.
    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
    [hip.step, trunk_top.step]
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2026-09-21 Fix right/left_hip_roll origin and update PETG-CF mass/inertia for 8 links
    hip_roll origin x was stale relative to commit 90fb138 ("Close 17.5mm gap
    between hip roll-mount flange and hip_block free horn"), which changed
    hip.step after the URDF was last regenerated (1b83c72). The joint's
    rotation axis maps to local +X in the hip frame, so the 17.5mm closure
    reduces |x| from 37.5mm to 20mm on both sides.
    Also updates mass/inertia for the links that map 1:1 to a single printed
    PETG-CF part plus only small screws (foot, femur, shoulder, hip and their
    mirrored pairs), using solid-body volume from Fusion times 1.25 g/cm3
    and scaling the existing inertia tensor by the same mass ratio (COM
    unchange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
    [robot.urdf]
2026-09-21 Fix head link mass/inertia using real servo mass instead of stale composite value
    The 'head' link bundles roll_servo_cradle (now PETG-CF) and an XL330
    neck servo. Its old mass (174.049g) did not correspond to either the
    bracket's real volume or the servo's real spec mass, so rather than
    scale it by a ratio, this rebuilds it from real values: 8.834g
    (roll_servo_cradle, solid PETG-CF from Fusion volume) + 18g (XL330-M288-T
    datasheet mass) = 26.834g. Inertia is scaled from the old tensor by the
    resulting mass ratio as an approximation; COM is left unchanged.
    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
    [robot.urdf]
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2026-09-21 Sync MJCF meshes: add 3-DOF neck, refresh stale hip/pelvis/foot, fix femur scale
    [camera_cover.stl, foot__configuration_right.stl, hip.stl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]
2026-09-21 Tighten neck roll/pitch and hip roll joint limits; add camera PCB mesh
    Update robot.urdf joint limits to user-specified ranges:
    - neck_roll: +/-45deg -> +/-25deg
    - neck_pitch: +/-45deg -> -90deg (up) / +25deg (down), matching the
    sign convention of robot.xml's neck_pitch (Ry(+) tilts local +X to -Z)
    - right/left_hip_roll: +/-35deg -> +/-25deg
    Also add the ELP-3DGS1200P01-H120 stereo camera PCB mesh to the MJCF
    assets, alongside the other exported part meshes.
    [elp-3dgs1200p01-h120.stl, robot.urdf]
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2026-09-21 Fix neck/hip mesh alignment and joint origins from live CAD; add neck servo meshes
    Applied to both robot.urdf and robot.mjcf, verified against the live
    Fusion 360 model on 2026-09-21 (all 21 joint axes and 69/70 mesh
    placements now agree to 0.000mm):
    - Add visual meshes for the 2 neck servo instances (xl330_without_horn
    in head and in roll_pitch_link), previously omitted.
    - Fix head yaw axis: sat 15mm behind the real CAD servo axis.
    - Fix neck_pitch axis (camera_cover body origin): sat 5mm below the
    real CAD servo axis. The camera_cover mesh itself was already
    correct; only the axis was off, matching the "cover looks right but
    the neck axis is a bit low" report.
    - Fix roll_pitch_lin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
    [robot.urdf, robot.xml]
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2026-09-21 Add collision geometry to URDF; rebuild foot sole collision from live CAD
    robot.urdf previously carried no <collision> elements at all. It now
    mirrors every collision primitive already defined in robot.xml
    (trunk/pelvis, radius, hip_dbl_block, femur, tibia, ankle_dbl_block,
    foot), converting MuJoCo quaternions to URDF rpy and doubling MJCF's
    half-extents to URDF's full box/cylinder sizes.
    The foot sole collision (both files) is rebuilt from the live CAD to
    match the new foot geometry, whose sole size and shape changed from
    the previous revision. The sole is a single flat face whose outer
    edge sits exactly on the mesh's true boundary; it's approximated by 6
    nested boxes forming an inscribed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
    [robot.urdf, robot.xml]
2026-09-21 Add XC330-T288-T bam actuator identification and MJCF/URDF collision viewer
    Adds tools/actuator_id/: a registry-based bam (Better Actuator Models)
    record/fit pipeline for identifying XC330-T288-T servo parameters via a
    pendulum testbench, since bam has no published XC330 identification (only
    XL330 and a few others). motors.py's registry makes adding a future motor
    type a one-entry addition. Also includes a parametric pendulum-arm STL
    generator sized to bolt onto this robot's existing servo horn pattern.
    Updates src/constants.py's PROXY_KT/PROXY_R from a real fit (30 recordings
    across 3 trajectories) instead of the previous datasheet-derived/XL330-borrowed
    placeholders.
    Also adds src/debug/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
    [pendulum_arm.stl]
2026-09-22 Use the identified XC330-T288-T bam model in the interactive sim viewer
    mujoco_controller.py was still loading the bundled xl330/m6 preset from
    before the XC330 swap. Point it at tools/actuator_id/xc330_params.json
    (a real identification against a physical XC330-T288-T) instead, registering
    "xc330" in bam's actuator registry the same way tools/actuator_id/fit.py
    already does, since bam has no built-in definition for it.
    [mujoco_controller.py]
2026-09-22 Update walk policy with the neck-aware training run
    Replace src/agents/walk.onnx with the policy exported from
    mjlab_microban's 2026-09-22_02-54-27 training run (model_14999.pt),
    the first run trained against the synced robot model that includes
    the neck (neck_roll/neck_pitch) as real bodies. The neck is excluded
    from the policy's action/observation space and stays at its default
    pose; the remaining 18 joints keep the same order and action scale as
    the previous policy, so this is a drop-in replacement for WalkMove.
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2026-09-22 Add NetworkInputSource to receive teleop bridge commands over UDP
    Adds foot_target/hand_target to UserInput (trunk-relative offsets,
    matching FootTargetCommand/HandTargetCommand in mjlab_microban), and a
    UDP+JSON input source that receives them from microban_teleop (a
    separate PC running the VR bridge).
    Every field is independently optional in both the wire format and
    UserInput itself, falling back to the neutral default rather than
    requiring the whole packet — the same rule the training env follows for
    missing keypoint targets. A dead network link (no packet within
    stale_after_s) also falls back to a fully-neutral UserInput instead of
    repeating the last command, so a lost connection can'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
2026-09-22 Fix sim_main.py: bam API drift and foot/floor spawn penetration
    sim_main.py hadn't been run in a while and had bit-rotted against the
    installed bam version: BamController's constructor param is now
    vin_drop_resistance (was vin_drop_gain), it no longer takes max_current,
    and it no longer has a .reset() method (replaced both calls with
    resetting .last_ts directly, since set_q_target already gets called
    fresh every tick from sync_write_goal_position — the actual reason
    BamController.reset() existed was to avoid a stale dt after a mid-sim
    manual reset).
    Also fixed the hardcoded initial spawn height (0.165 -> 0.175): measured
    directly, NEUTRAL_POSE at 0.165 penetrates the floor by up to ~9mm (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
    [mujoco_controller.py]
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2026-09-25 Update getup.onnx with the final trained checkpoint
    Re-exported from mjlab_microban's Mjlab-Getup-Microban training
    (iteration 33999 of a resumed run building on standing_pose/
    hip_roll_pose weights of 480 plus a home_stillness trembling-
    suppression term), after reverting an experimental 4x head_height
    weight escalation that was measured to stall curriculum progression.
    Same 60-dim (no foot_contact) observation schema as before, matching
    src/moves/getup.py's own build_observation exactly.
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2026-09-26 Update getup.onnx, re-enable auto getup, gate head tracking on right trigger
    - Update getup.onnx to the latest getup training checkpoint (60-dim obs,
    18-dim actions, no foot_contact).
    - Re-enable Scheduler's auto get-up-on-fall trigger while the policy is
    running: the raw/pre-clip observation bug in getup.onnx that made this
    unsafe has been fixed and redeployed.
    - Show Policy: ON/OFF in the IMU/log display.
    - Gate PICO head-orientation tracking on the same right-trigger deadman
    as hand/arm tracking (arm_tracking_enabled), instead of applying it
    unconditionally.
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2026-09-26 Hold individual servo values through transient bus failures
    [robot_controller.py]
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2026-09-26 Combine servo feedback reads and isolate transient bus failures
    [observer.py, robot_controller.py]
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2026-09-27 Restore network-input staleness backstop; fix test rot from recent hardening
    NetworkInputSource.read() lost its elapsed-time staleness check when the
    "replay through a live-session gap" feature was added: after a total UDP
    transport loss (bridge crash, cable pull), it would replay the last
    commanded state forever with no cutoff, instead of freezing torque/goal
    state and requiring a fresh authenticated packet. Reinstated the
    stale_after_s check, distinct from the (still working) same-session
    false/false dropout replay.
    Also updates several tests that had fallen behind recent intentional
    behavior changes (balance_only auto-walk on R3, KP_HARDWARE_NEUTRAL vs
    KP_DEFAULT split, get-up model_read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
    [test_policy_selector.py]
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2026-09-27 Fix legacy walk foot_target regression; update tests for v12 target independence
    network_input.py's new exact-key-set check on foot_target/hand_target
    was raising for plain "walk" packets with an odd-shaped (not
    malformed-type) target, discarding the whole packet instead of just
    that field. Scope the strict check to pico_teleop packets only, where
    it's meaningful.
    Also updates test_pico_hybrid.py, test_network_input.py, and
    test_policy_selector.py for the already-deliberate v12 changes pulled
    in this session: v12 no longer clamps targets to compiled soft limits
    (sends the finite raw target as-is), and foot/hand targets are now
    validated and reported independently rather than as an atomic pa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
    [test_pico_hybrid.py, test_policy_selector.py]
2026-09-27 Drop now-vacuous NEUTRAL_POSE inequality check in PICO arm release test
    The new upright-centered NEUTRAL_POSE happens to share the same
    shoulder-pitch value as PICO_ARM_HOME_RAD, so this assertion no longer
    distinguishes anything -- the release target is still verified exactly
    against PICO_ARM_HOME_RAD by the loop above it.
    [test_pico_arms.py]
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2026-09-27 v3: remove get-up's mistaken 0.5 rad/s active-policy rate limit
    _POLICY_MAX_TARGET_SPEED_RAD_S rate-limited the ACTIVE get-up policy's
    own commanded target to 0.5 rad/s, the same value as
    _RECOVERY_SLEW_RATE_RAD_S (the deliberately slow, gentle torque-off->on
    return-to-neutral). These are different phases: the recovery slew is a
    genuine safety behavior for a limp-to-torqued transition, but the
    active policy executing a learned recovery motion was never meant to
    be rate-limited at all -- and wasn't, before this constant was
    introduced. Modeling that same cap in mjlab_microban's training
    simulation (now fixed in a matching commit there) made a physically
    fast get-up motion impossible to even e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
2026-09-27 Fix getup.py's action clip: still a stale blanket +-1.57, not per-joint
    Training moved the get-up action's clip from a blanket +-1.57 rad range to
    each joint's own soft limit (MICROBAN_BODY_JOINT_SOFT_LIMITS) a while back --
    export_getup_onnx.py has embedded genuinely per-joint, asymmetric bounds
    (e.g. right_hip_yaw -3.927/+0.785 rad) in action_clip_lower/upper metadata
    ever since, and microban_getup_runner.py requires exactly this clip for v3
    contract validity. But this file's own validity check and runtime clamp were
    never updated to match: clip_valid still asserted every value was within
    0.001 of a flat +-1.57, and _action_clip was a single (lo, hi) tuple applied
    uniformly to all 18 joint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
2026-09-27 Share the recovery-slew constants instead of triplicating bare literals
    getup.py's _RECOVERY_SLEW_RATE_RAD_S/_RECOVERY_MIN_DT_S/_RECOVERY_MAX_DT_S
    (0.5 rad/s, dt clamped to [0.001, 0.1]) were reimplemented as unlabeled bare
    literals in two more places in scheduler.py (_step_hardware_neutral and
    _failed_getup_hold_command) -- three independent copies of the same
    recovery-slew math, only one of them named.
    Currently consistent, but this is the same raw material that caused the
    now-fixed slew-rate/action-rate-limit conflation: an unlabeled constant
    duplicated across files with no shared source of truth, where retuning one
    copy silently doesn't propagate to the others. Found during the audit th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
2026-09-30 Revert "Set upright centered A-button neutral pose"
    This reverts commit 717923bfdd70e995a12890b4438491ea59d30b7d.
    The new upright/straight-leg pose (hip pitch +1.198 deg, ankle pitch
    -1.198 deg, shoulder pitch 0 deg) was mathematically centered (CoM
    directly over the sole contact patches) but has proven worse in
    practice across this session's training work than the previous
    crouched pose (hip pitch -10 deg, ankle pitch 0 deg, shoulder pitch
    +10 deg): the deployed PICO v12 walking actor was never touched by
    this change (PICO_TELEOP_HOME_POSE already pinned its own historical
    HOME independently), and new training built on the centered pose this
    session (Tracking, Teleop-Upright-Fullbody, get-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
    [constants.py, test_pico_hybrid.py]
2026-09-30 Install the v4 HOME-stance get-up policy
    Checkpoint: mjlab_microban run 2026-09-30_12-20-47_v4_S1D_posture_delay_ft,
    model_3500.pt. This is stage 2 of the two-stage recipe (HOME-stance
    rewards, then fine-tuned under 0-3 tick simulated IMU delay).
    Measured in sim (64 envs, all fallen starts, delay plus sensor noise):
    - stood up and stayed up in 61/62 and 54/54 (two seeds); median ~3 s to
    stand; no falls after standing;
    - 61/62 even with 0-5 tick delay;
    - feet 10.0 cm apart (HOME 9.4 cm), 0.2 cm stagger, every leg joint within
    4 deg of HOME;
    - no falls after 0.2 m/s fore-aft kicks while standing.
    Known remaining issue: joints tremble slightly while standing (~0.77 rad/s).
    The previous f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
2026-10-03 Harden the real-robot offset boundary after review
    - _read_core no longer accepts positions: its unused position branch would
    have skipped the offset; positions only come through _from_servo.
    - A typed -0.0 offset is normalised to +0.0 so zero entries never flip the
    sign of a zero reading.
    - Tests: pending-enable rejoin on both MOTOR_SIGN values, head poll with a
    -1 sign, an exact-zero reading on a -1 joint, -0.0 table, and the
    _read_core guard.
    - Docs: how to measure an offset; drop the "one spline tooth" example that
    may exceed the 0.2 rad cap; range comment says "strictly within".
    [constants.py, robot_controller.py, test_hardware_joint_offset.py]
2026-10-03 Drop the +-1.57 clip: policy targets bounded only by the servo's +-pi range
    Every policy (walking, PICO full-body tracking, get-up) now commands
    target = clip(HOME + raw_action * 1.0, -pi, +pi), the XC330's one-turn goal
    range in Position Control mode, matching mjlab_microban 94d2946
    (SERVO_TARGET_RANGE_RAD) and the get-up exporter's contract v5 (1290a1e).
    The previous-action observation stays the policy's raw output.
    - constants: POLICY_TARGET_CLIP_RAD -> SERVO_TARGET_RANGE_RAD = pi; add the
    servo goal range SERVO_GOAL_MIN/MAX_RAD = [-pi, pi - 2*pi/4096] (raw
    0..4095) and the 3-decimal CSV tolerance used for PICO metadata.
    - WalkMove: accept only walk_contract_version v3_centered_home_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
    [constants.py, robot_controller.py, test_hardware_joint_offset.py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]
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2026-10-03 Read each servo's mode and position limits at startup; saturate per servo
    RobotController now reads every servo's Operating Mode and Min/Max Position
    Limit (per ID, with retries) before starting the IMU. A servo answering with
    a mode other than Position Control (3), or with an empty limit range, stops
    startup with an error naming the joints. Each servo's goal saturation uses
    its own bounds (raw 0..4095 intersected with its limits, converted with
    rustypot's raw->rad mapping); the factory limits give exactly the old
    constants, so in-range goals and seed write-backs are unchanged. A silent
    servo keeps the full range with a warning, and narrower limits are printed
    once with their logical range a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
    [constants.py, robot_controller.py, test_hardware_joint_offset.py]
2026-10-03 Harden the servo configuration read: exact edges, confirmed reads, late check
    - servo_goal_bounds nudges a narrowed Max edge up, so rustypot's truncation
    lands on the limit instead of one tick short; refuse ranges with fewer than
    two raw values.
    - Narrowed limits and a non-position mode must read the same twice; a single
    stray reply now leaves the full range (and pending) instead of pinning or
    refusing a joint.
    - A servo silent at startup is read again when it first answers a position
    read (before its rejoin seed / torque ON); limits are applied then, and a
    non-position mode stops the runtime.
    - Refusals raise ServoConfigurationError (not a RuntimeError, which the
    scheduler may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
    [robot_controller.py, test_hardware_joint_offset.py]
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2026-10-05 Apply the training gate's norm-wise ONNX parity rule
    The training ONNX gate bounds each of its 64 random full-83 samples by
    atol + rtol * max|expected| (rtol 1e-6): the corpus drives raw actions to
    tens of radians and float32 accumulation differences scale with the output.
    The robot capped the absolute errors at atol alone, so a gate-passing package
    (onnxruntime CPU error 2.48e-5 at max|expected| 46.6, bound ratio 0.45) was
    refused.
    A package that declares v12_onnx_parity_rule now gets the stage validator's
    cap atol + 1e-6 * v12_onnx_parity_max_abs_expected_output (magnitude <= 200),
    with both bound ratios <= 1. The legacy zero-extra parity stays a plain atol
    bound, and a package without th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
    [test_pico_hybrid.py]
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2026-10-05 Derive the robot tests' HOME-bound values from config/home_pose.yaml
    On a branch of another HOME (each branch = same code + its own
    config/home_pose.yaml + its own policies) the suite failed in 34 tests that
    hard-coded the centered HOME: the v12 fixture's target frames and recipe,
    the get-up contract/stamp, upright gravity in the hand-back balance tests,
    the smoke-corpus gravity row, the malformed-yaml mutations and the
    any-trunk test's use of the installed yaml and agents. They now read the
    loaded HOME (HOME_CONTRACTS, PICO_V12_TARGET_FRAME, HOME_PROJECTED_GRAVITY,
    HOME_TRUNK_PITCH_RAD); the centered literals stay pinned in centered-only
    checks, and the any-trunk test uses a frozen tests/f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
    [test_pico_hybrid.py]
2026-10-05 Refuse dry-run PICO packages and re-package the centered policy
    The training repository's scripts/retrain_all_for_home.py --dry-run now
    marks its PICO package with dry_run_not_deployable. pico_hybrid refuses
    such a package (before any inference) unless MICROBAN_ALLOW_DRYRUN_POLICY=1,
    which only the dry run's own validator and test calls set, so a DRYRUN
    robot commit pushed by mistake cannot run its policy.
    pico_hybrid.py is a runtime-identity file, so pico_teleop.onnx is
    re-packaged from the same centered checkpoint and gate
    (2026-10-05_03-31-01_c20k_v12_pr_10100_to15000/model_14999.pt, gate
    b6c24d04...) with the training home-config packager 1059fe3 against this
    tree: sha256 13deb3be...;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
    [test_pico_hybrid.py]
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2026-10-06 Check every learned policy against one contract and its startup self-test
    Walk, get-up and PICO are now admitted by src/policy_contract.py alone
    (contract microban-policy-1): one metadata schema, the HOME stamp of
    config/home_pose.yaml, the reviewed recipe id of each kind, and a startup
    self-test that runs the observations recorded from the exported
    checkpoint's evaluation rollouts through ONNX Runtime and requires the
    recorded training actions back. Run-specific values (file and checkpoint
    SHA-256, PICO's frozen walker) live in src/agents/manifest.json, which the
    installer writes; it no longer rewrites robot code or tests.
    The PICO package no longer pins the SHA-256 of twelve robot source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
    [constants.py, main.py, mujoco_controller.py]
2026-10-06 Hold position at P900 on all 21 joints, whatever the hold follows
    The PICO-unavailable hold raised only the 18 policy joints after get-up, so
    head, neck_roll and neck_pitch stayed at P125 (the neck sags 7-9 degrees),
    and a hold after a PICO runtime failure kept every joint at P125. The hold
    now re-seeds its goals and writes P900 to all 21 joints on its first step
    after every start, and returns to neutral at P900 on all 21; the get-up
    start flag it no longer needs is removed.
    [test_policy_selector.py]
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2026-10-08 Track uv.lock and follow the locked bam API in the simulator
    Lock the robot and simulator dependencies (the Makefile already syncs
    with --frozen). The locked better-actuator-models takes
    vin_drop_resistance, has no max_current or reset(), and resets data.qpos
    in its constructor, so the simulator spawns the robot again afterwards.
    [mujoco_controller.py]
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2026-10-08 Upgrade to XC330-T288-T servos, a 3S battery and a 2-DOF neck with a stereo camera
    Redesigned printed parts (PETG-CF), a roll + pitch neck (IDs 52, 53)
    carrying an ELP-3DGS1200P01-H120 stereo camera, the CAD, MJCF/URDF with
    CAD mass properties and collision shapes, the BOM and assembly notes,
    and the XC330 actuator constants from the identification. The simulator
    uses the identified XC330 model.
    [ELP-3DGS1200P01-H120.sldprt, ELP-3DGS1200P01-H120.step, battery.stl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]
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2026-10-08 Hold the last motor goals through serial bus errors
    With MICROBAN_SERIAL_HOLD_LAST_ON_ERROR=1, a failed feedback read or goal
    or torque write no longer stops the control loop: the scheduler resends
    the last goals and keeps B effective. After 0.3 s of errors the input
    source's motion is inhibited, and the moves drop their stale policy
    history when the bus recovers.
    [main.py]
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

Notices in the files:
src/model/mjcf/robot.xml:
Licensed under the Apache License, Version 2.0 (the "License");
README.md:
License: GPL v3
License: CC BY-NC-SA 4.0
